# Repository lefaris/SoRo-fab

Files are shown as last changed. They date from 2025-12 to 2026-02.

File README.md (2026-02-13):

# SoRo-fab: Open-Source Fabrication for Motor-Tendon Actuated Soft Robots


[]()

This repository provides a detailed, standardized fabrication methodology for creating untethered terrestrial soft robots (uTerreSoRo) with comprehensive documentation of design principles, manufacturing best practices, and performance evaluation frameworks.  This is supplementary material for the in-progress paper **An Open-Source Fabrication Strategy and Repeatability Analysis for Motor-Tendon Actuated (MTA) Soft Robots** that will be submitted soon.

uTerreSoRo prototype

---

## Overview

> **Work in Progress**: This repository is being actively developed alongside the paper submission process. Additional materials including CAD files, detailed fabrication guides, and extended documentation will be added progressively. Star/watch this repository for updates!

Soft robotics is a rapidly advancing field, but soft robots (SoRos) remain rare in everyday applications due to complexities in design and lack of consistency in fabrication techniques. Unlike rigid robots with standardized manufacturing pipelines, SoRos still lack broadly adopted methodologies and transparent reporting of fabrication practices.

This work addresses these challenges by providing:

- **Detailed fabrication methodology** for motor-tendon actuated soft robots
- **Critical design principles** including cavity optimization and bio-inspired stiffness gradients  
- **Best practices** for motor anchoring and rigid-soft integration
- **Comprehensive repeatability and reproducibility analysis** across multiple prototypes
- **Task-based performance evaluation** with statistical validation

---

## Repository Structure

```
SoRo-fab/
├── PCBs/                     # PCB designs for different iterations
│   ├── KiCAD_3limbs/         # Gerber/drill/schematic files for 3 limb SoRo
│   ├── KiCAD_4limbs/         # Gerber/drill/schematic files for 4 limb SoRo
│   └── RSC_4limb_big_mode/   # Design files for in-person large 4 limb PCB fab
├── design_files/             # CAD files of hub, hub cap, and mold + pulley (coming soon)
├── experiments/              # Experimental data and analysis scripts
│   ├── raw_data/             # Marker tracking data
│   ├── analysis/             # Python covariance confidence ellipse code
│   └── statistical_tests/    # (Coming soon) Repeatability/reproducibility analysis
├── media/                    # Images, videos, and supplementary materials
└── README.md                 # This file

Coming Soon:
├── fabrication_guide/         # Detailed step-by-step instructions
├── firmware/                  # Microcontroller code and gait sequences
└── docs/                      # Extended documentation
```

---

## Current Repository Contents

### design/
CAD files for SoRo
- Semi-flexible hub with motor mating and ziptie holes
- Hub cap for sealing with cable hole
- Battery enclosure
- Limb mold (coming soon)
- Pulley (coming soon)

uTerreSoRo Mechatronics

### PCBs/
Custom 2-layer PCB design for the uTerreSoRo control system:
- Gerber files for manufacturing (in-person fab lab and external manufacturer)
- Schematic diagrams showing circuit design
- Board layouts
- Drill files

**Key Features**:
- Seeeduino XIAO integration
- 4x TB6643KQ motor driver support
- I2C interface for 6-axis IMU
- LiPo battery management enables tetherless capabilities
- Compact design fits in central hub

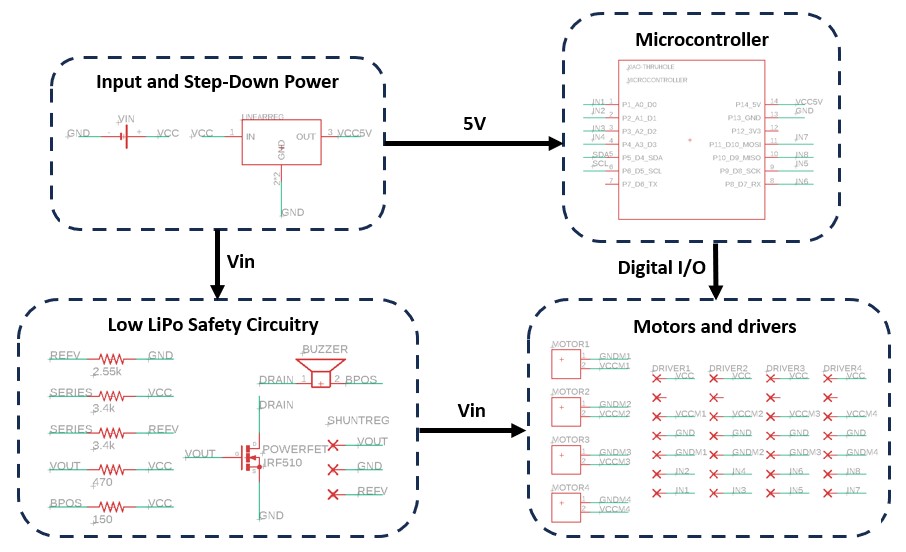
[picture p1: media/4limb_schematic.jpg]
uTerreSoRo Schematic


### experiments/
Experimental data and analysis code for repeatability/reproducibility evaluation:
- Gait-based twist locomotion data
- Covariance confidence ellipse script for consistency analysis

**Includes**: Data from all three independently fabricated prototypes (Blue, Black, Purple)

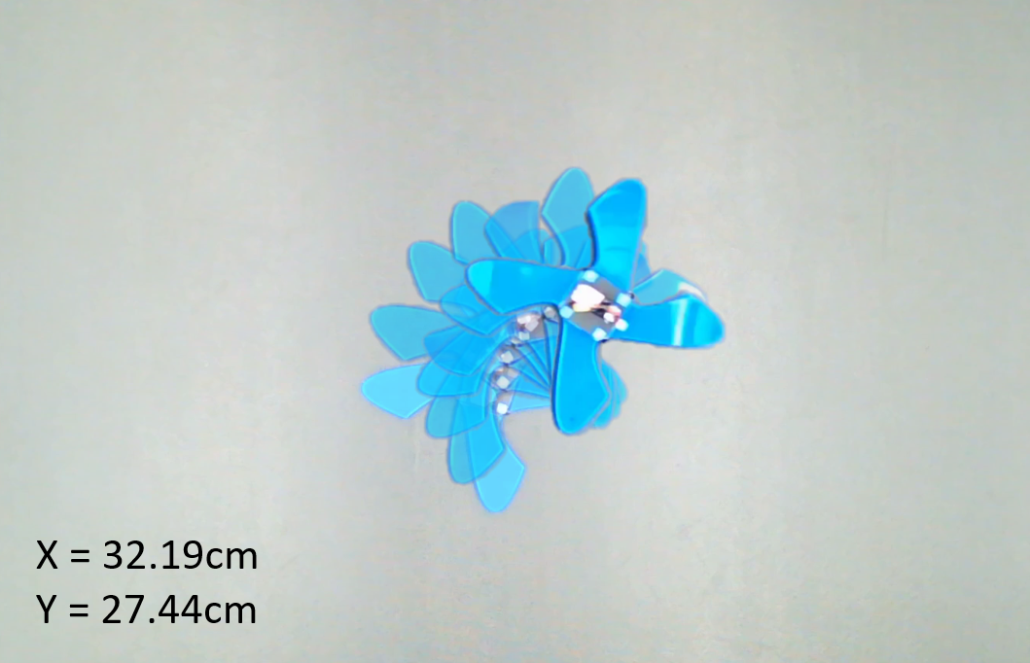
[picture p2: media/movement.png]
uTerreSoRo Experiments


### media/
Visual documentation of the fabrication process and robot performance:
- Fabrication process step-by-step photos
- Completed robot prototype images
- Supplementary materials for the paper

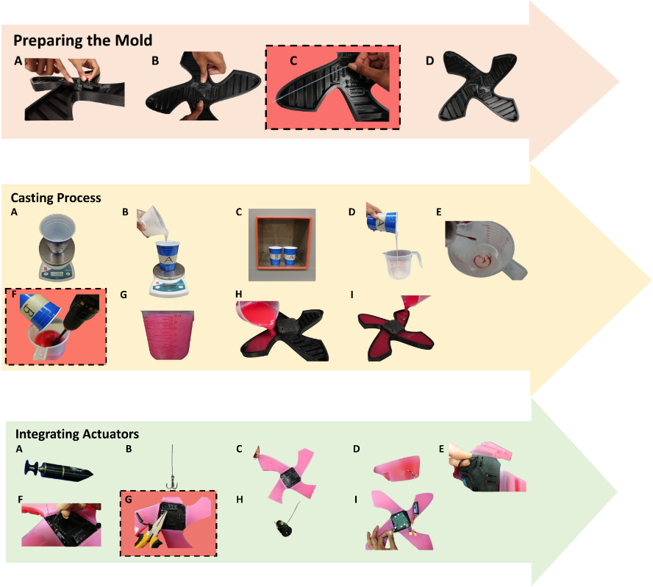
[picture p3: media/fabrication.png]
Fabrication Process

---

## Getting Started

### Prerequisites

**Materials**
- Dragon Skin Silicone Rubber (30A shore hardness) for limbs
- NinjaFlex TPU (85A shore hardness) for hub
- nGen filament for molds
- Braided fishing line (high-strength) for tendons
- PTFE tubing for tendon paths
- Two-pronged fishing hooks for tendon anchoring

**Equipment**
- 3D printer
- Vacuum chamber
- Power drill with mixing attachment
- Mold release agent
- Scale (accurate to 1g)
- Zip ties and pliers

**Electronics** 
- Seeeduino XIAO microcontroller
- 4x Maxon DC motors
- 4x TB6643KQ full-bridge motor drivers
- 5V voltage regulator
- IRF510 power MOSFET
- shunt regulator
- buzzer
- resistors
- JST connectors
- 11.4V 1.1Ah LiPo battery (3-cell)
- Custom PCB

### Installation

1. **Clone the repository**
   ```bash
   git clone https://github.com/lefaris/SoRo-fab.git
   cd SoRo-fab
   ```

2. **Explore existing materials**
   - PCB designs are in `PCBs/`
   - Hub files are in `design/`
   - Experimental data and analysis scripts in `experiments/`
   - Images and videos in `media/`

3. **Coming soon**
   - CAD files for molds
   - Detailed fabrication guide with photos
   - Firmware and control code
   - Extended documentation

**Note**: This repository is actively being developed. Additional materials including fabrication guides and firmware will be added as the paper progresses through review.

---

## Citation

If you use this fabrication methodology in your research, please cite (coming soon)

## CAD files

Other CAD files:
design/uTerreSoRo_Hub_Cap.f3d
design/uTerreSoRo_battery_cap.f3d
design/uTerreSoRo_hub_new_zipties.f3d

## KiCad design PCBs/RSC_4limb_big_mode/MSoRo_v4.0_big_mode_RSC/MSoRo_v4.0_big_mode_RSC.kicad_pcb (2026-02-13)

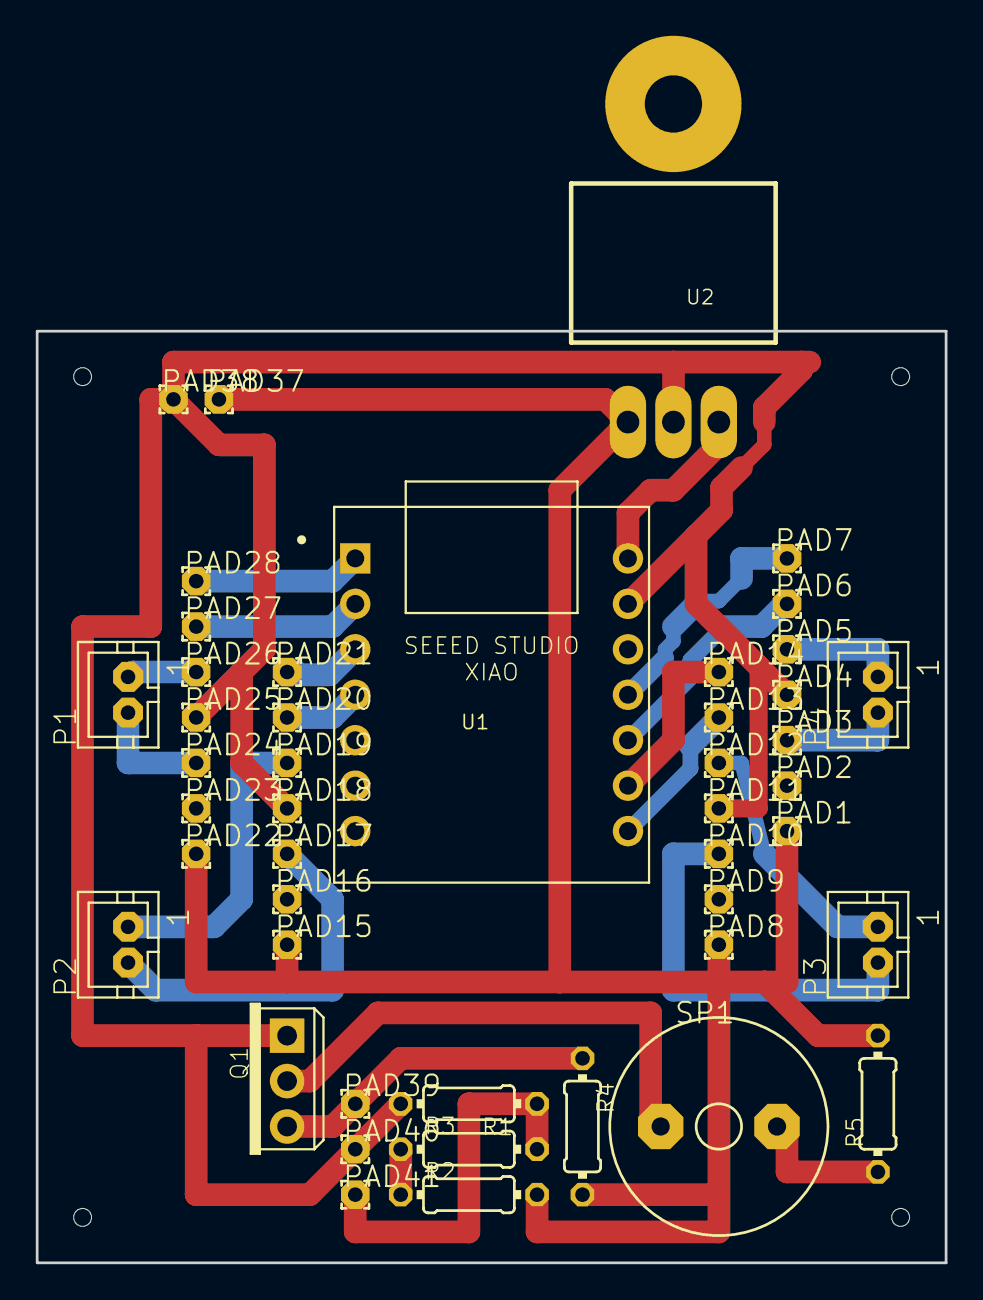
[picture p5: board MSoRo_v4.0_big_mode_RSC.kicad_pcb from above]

Board: 16 copper layers, 50.8 x 52.1 mm, 50 parts (0 on the bottom side), 24 nets.

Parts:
@HOLE0, @HOLE1, @HOLE2, @HOLE3: (no value)
P1, P2, P3, P4: JST-PH2
PAD1, PAD2, PAD3, PAD4, PAD5, PAD6, PAD7, PAD8, PAD9, PAD10, PAD11, PAD12, PAD13, PAD14, PAD15, PAD16, PAD17, PAD18, PAD19, PAD20, PAD21, PAD22, PAD23, PAD24, PAD25, PAD26, PAD27, PAD28, PAD37, PAD38, PAD39, PAD40, PAD41: 1,6_0,8
Q1: IRF510; TO220_ALT
R1: 2.55k; 0204_7
R2, R3: 3.4k; 0204_7
R4: 470; 0204_7
R5: 150; 0204_7
SP1: AL60P
U1: XIAO-THRUHOLE; XIAO-GENERIC-THRUHOLE-MODULE14P-2.54-21X17.8MM
U2: TO-220

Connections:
BPOS: R5.1, SP1.2
DRAIN: Q1.2, SP1.1
GND: PAD4.1, PAD11.1, PAD18.1, PAD25.1, PAD38.1, PAD40.1, Q1.1, R1.2, U1.13, U2.2, U2.HEAT
GNDM1: P1.1, PAD26.1
GNDM2: P2.1, PAD19.1
GNDM3: P3.1, PAD12.1
GNDM4: P4.1, PAD5.1
IN1: PAD28.1, U1.1
IN2: PAD27.1, U1.2
IN3: PAD21.1, U1.3
IN4: PAD20.1, U1.4
IN5: PAD14.1, U1.9
IN6: PAD13.1, U1.8
IN7: PAD7.1, U1.11
IN8: PAD6.1, U1.10
REFV: PAD41.1, R1.1, R3.2
SERIES: R2.1, R3.1
VCC: PAD1.1, PAD8.1, PAD15.1, PAD22.1, PAD37.1, R2.2, R4.2, R5.2, U2.1
VCC5V: U1.14, U2.3
VCCM1: P1.2, PAD24.1
VCCM2: P2.2, PAD17.1
VCCM3: P3.2, PAD10.1
VCCM4: P4.2, PAD3.1
VOUT: PAD39.1, Q1.3, R4.1

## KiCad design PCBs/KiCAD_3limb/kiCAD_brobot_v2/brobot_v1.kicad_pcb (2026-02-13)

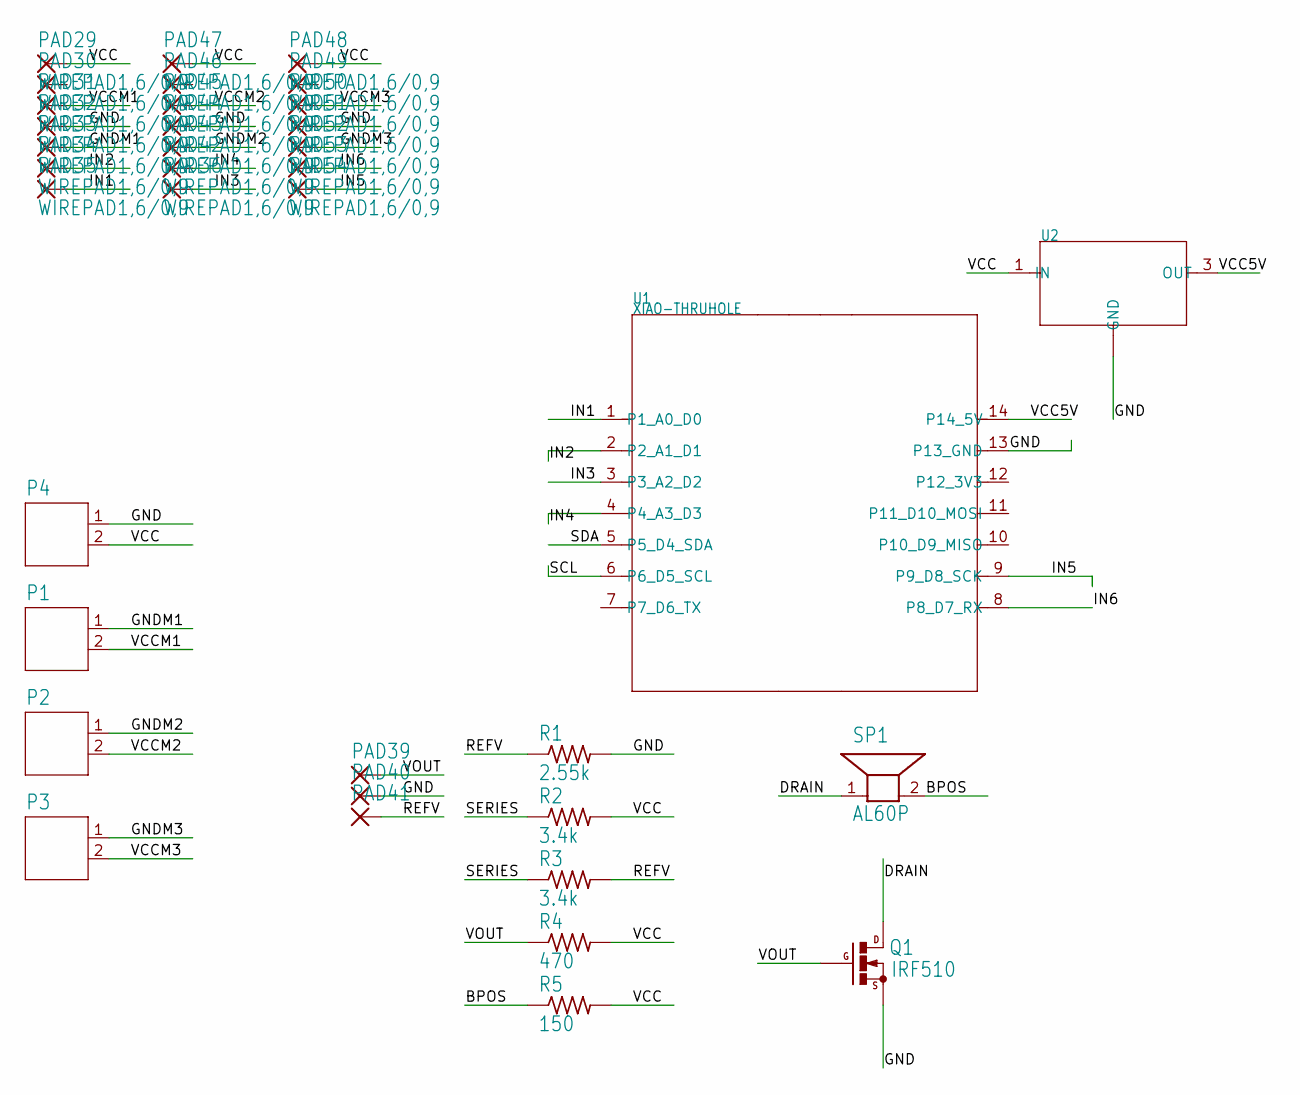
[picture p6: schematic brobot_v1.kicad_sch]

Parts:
P1, P2, P3, P4: JST-PH2
PAD29, PAD30, PAD31, PAD32, PAD33, PAD34, PAD35, PAD36, PAD42, PAD43, PAD44, PAD45, PAD46, PAD47, PAD48, PAD49, PAD50, PAD51, PAD52, PAD53, PAD54: WIREPAD1,6/0,9; 1,6_0,9
PAD39, PAD40, PAD41: 1,6/0,8; 1,6_0,8
Q1: IRF510; TO220_ALT
R1: 2.55k; 0204_7
R2, R3: 3.4k; 0204_7
R4: 470; 0204_7
R5: 150; 0204_7
SP1: AL60P
U1: XIAO-THRUHOLE; XIAO-GENERIC-THRUHOLE-MODULE14P-2.54-21X17.8MM
U2: PMIC-ST-L7805CV(TO-220); TO-220

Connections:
BPOS: R5.1, SP1.2
DRAIN: Q1.2 (D), SP1.1
GND: P4.1, PAD32.1, PAD40.1, PAD44.1, PAD51.1, Q1.1 (S), R1.2, U1.13 (P13_GND), U2.2 (GND), U2.HEAT (GND)
GNDM1: P1.1, PAD33.1
GNDM2: P2.1, PAD43.1
GNDM3: P3.1, PAD52.1
IN1: PAD35.1, U1.1 (P1_A0_D0)
IN2: PAD34.1, U1.2 (P2_A1_D1)
IN3: PAD36.1, U1.3 (P3_A2_D2)
IN4: PAD42.1, U1.4 (P4_A3_D3)
IN5: PAD54.1, U1.9 (P9_D8_SCK)
IN6: PAD53.1, U1.8 (P8_D7_RX)
REFV: PAD41.1, R1.1, R3.2
SCL: U1.6 (P6_D5_SCL)
SDA: U1.5 (P5_D4_SDA)
SERIES: R2.1, R3.1
VCC: P4.2, PAD29.1, PAD47.1, PAD48.1, R2.2, R4.2, R5.2, U2.1 (IN)
VCC5V: U1.14 (P14_5V), U2.3 (OUT)
VCCM1: P1.2, PAD31.1
VCCM2: P2.2, PAD45.1
VCCM3: P3.2, PAD50.1
VOUT: PAD39.1, Q1.3 (G), R4.1

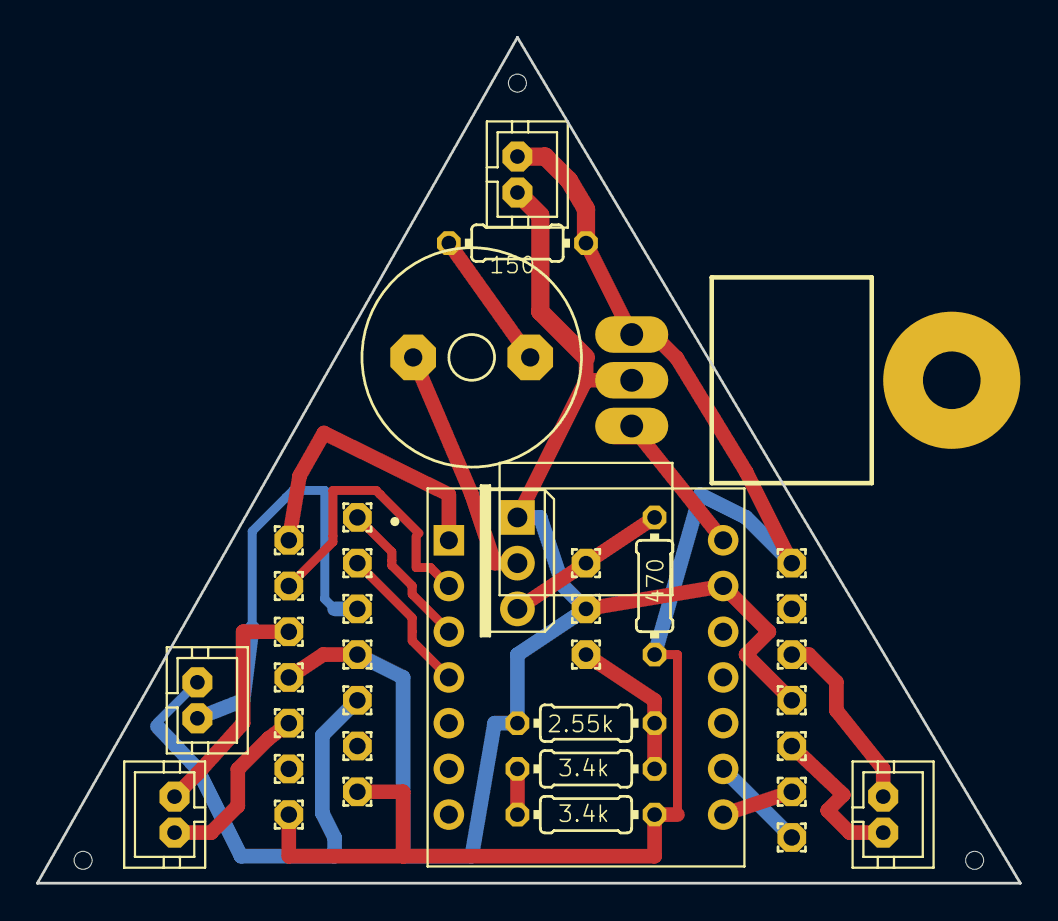
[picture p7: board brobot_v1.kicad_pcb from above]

Board: 16 copper layers, 54.6 x 47.0 mm, 40 parts (0 on the bottom side), 20 nets.

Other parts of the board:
@HOLE0, @HOLE1, @HOLE2: (no value)

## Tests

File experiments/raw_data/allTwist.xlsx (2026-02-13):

Black (x,y,theta) |  |  | Blue (x,y,theta) |  |  | Purple (x,y,theta)
pose11 | pose12 | pose13 | p1 | p2 | p3 | pur1 | pur2 | pur3 |  | Black | Blue | Purple
-0.1361065002 | 0.7648523422 | -4.120429117 | 0.1874225642 | 0.7351847642 | -3.292302718 | 0.5383279231 | 0.7085753038 | -3.970353476 | STD DEV X | 0.04643353685 | 0.08146766643 | 0.1722574892
-0.131178489 | 0.8183995388 | -3.890566765 | 0.1381635116 | 0.6192531855 | -3.194679928 | 0.6620063048 | 0.900824489 | -5.04509589 | STD DEV Y | 0.05331519131 | 0.05458927221 | 0.2058866361
-0.1013089353 | 0.7627754714 | -3.685951207 | 0.1303507214 | 0.6385259774 | -3.05108575 | 0.6144737883 | 0.917081467 | -5.346707983 | STD DEV Theta | 0.3987964755 | 0.3719008826 | 1.153256027
-0.1649015439 | 0.7519305402 | -3.863593459 | 0.1474396188 | 0.6286551586 | -3.0994533 | 0.6020197031 | 0.8817419951 | -5.211466681 | AVG X | -0.1194410136 | 0.02935242006 | 0.3522590005
-0.1273748317 | 0.7392478509 | -3.713164335 | 0.1508818403 | 0.6063402211 | -3.348548357 | 0.5772870454 | 0.9074275587 | -5.299818125 | AVG Y | 0.7912548181 | 0.6176606471 | 0.574851499
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

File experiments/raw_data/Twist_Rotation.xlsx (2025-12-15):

black x | black y | black theta | blue x | blue y | blue theta | purple x | purple y | purple theta
0.1597773309 | -0.3998124116 | 0.2044879742 | 0.8767294008 | -0.5490908105 | 0.1714134294 | 0.7150906802 | 0.1530229161 | 0.1643252542
0.3884209268 | -0.8649532159 | 0.1498022634 | 1.018945936 | -0.988370134 | 0.1105667388 | 0.4408088981 | -0.711431997 | 0.1338795504
0.417276857 | -0.5270223164 | 0.1554086667 | 0.88113734 | -1.097950095 | 0.1182033763 | 0.4519723403 | -0.7490320823 | 0.1265435527
0.4898809251 | -0.6968537655 | 0.1680021232 | 0.9442978538 | -1.015043245 | 0.1154456831 | 0.2749186636 | -0.6889716068 | 0.1213296874
0.3112360577 | -0.3184625798 | 0.1483800691 | 1.006480338 | -1.061216363 | 0.1165848434 | 0.323770189 | -0.6972886897 | 0.1355327829
0.630692069 | -0.6718514586 | 0.1561858659 | 0.7927088756 | -1.030779899 | 0.1016820127 | 0.4377500313 | -0.4874261325 | 0.1312903321
0.4901104953 | -0.548193284 | 0.1447350683 | 0.6648566623 | -1.039129258 | 0.1126510332 | 0.3141015748 | -0.5954230498 | 0.147721601
0.5257322145 | -0.4241093249 | 0.15123105 | 0.6419943513 | -0.9519667234 | 0.1210436207 | 0.3246343255 | -0.3753447475 | 0.1437756672
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

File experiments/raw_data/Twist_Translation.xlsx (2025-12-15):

black x | black y | black theta | blue x | blue y | blue theta | purple x | purple y | purple theta
-0.1211481739 | 0.5626878693 | -0.05327041088 | 0.1231470916 | 0.5484201914 | -0.04256409066 | 0.4109508929 | 0.5155512484 | -0.05133017824
-0.1177141149 | 0.6026898782 | -0.05029866654 | 0.0895286321 | 0.461440431 | -0.04130198762 | 0.4997613833 | 0.6606122922 | -0.06522484027
-0.09319216521 | 0.5624101348 | -0.04765332195 | 0.08393976754 | 0.4754413077 | -0.0394455497 | 0.4629565713 | 0.6743942881 | -0.06912419144
-0.1408824474 | 0.5526561005 | -0.04994994579 | 0.0965925205 | 0.4685109394 | -0.04007086304 | 0.4541901888 | 0.6477656745 | -0.06737574256
-0.1120625517 | 0.5443420096 | -0.0480051432 | 0.09860789793 | 0.4522789886 | -0.04329125481 | 0.4355923689 | 0.6673690704 | -0.06851798225
-0.1412848339 | 0.5733135423 | -0.04426899662 | 0.06543249328 | 0.497420219 | -0.04530521987 | 0.4375409048 | 0.629194231 | -0.06836817723
-0.1247832712 | 0.5983889352 | -0.04114599163 | 0.07273609871 | 0.47117296 | -0.0338866478 | 0.4086106488 | 0.5513943818 | -0.06316257926
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
